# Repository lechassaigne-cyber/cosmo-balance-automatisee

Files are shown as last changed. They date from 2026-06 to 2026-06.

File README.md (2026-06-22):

# Système automatisé de pesée — Cosmo International Fragrances

> ⚠️ Projet en cours de développement — Stage avril–juillet 2026

**Auteur :** Léo Chassaigne  
**Période :** Avril – Juillet 2026  
**Entreprise :** Cosmo International Fragrances — Mougins (06)  
**Formation :** CESI École d'Ingénieurs — Spécialité Systèmes Électroniques et Électriques Embarqués (S3E)

---

## Contexte

Projet développé dans le cadre d'un stage de deuxième année au sein de la division Technology de Cosmo International Fragrances. L'objectif est de concevoir un système automatisé de pesée permettant de suivre l'évaporation de flacons de parfum au fil du temps, en remplacement des relevés manuels effectués par les équipes du laboratoire.

---

## Historique des versions

### V1 — Python / Mini Unit Scale (I2C)
Première version développée en Python sur Wio Terminal.  
Utilise des balances Mini Unit Scale communicantes via un bus I2C multiplexé (TCA9548A).  
Fonctionnelle sur 4 balances simultanées.

### V2 — Python / HX711
Remplacement des Mini Unit Scale par des cellules de charge associées à des modules HX711.  
Amélioration de la stabilité des mesures.  
Toujours en Python sur Wio Terminal.

### V3 — C++ / HX711 / reTerminal ← version actuelle
Réécriture complète du firmware en C++ sous PlatformIO (framework Arduino).  
Communication BLE Nordic UART Service vers le reTerminal (Raspberry Pi CM4).  
Réception et enregistrement automatique des données en CSV sur le reTerminal.  
Dashboard TFT sur le Wio Terminal (mode OVERVIEW / FOCUS).

---

## Matériel utilisé

| Composant | Rôle |
|---|---|
| Wio Terminal (Seeed Studio) | Microcontrôleur principal, affichage TFT, BLE |
| reTerminal (Raspberry Pi CM4) | Réception BLE, stockage CSV |
| Cellules de charge 1 kg | Mesure du poids |
| Modules HX711 | Amplification signal cellules de charge |
| TCA9548A | Multiplexeur I2C (jusqu'à 8 canaux) |
| Boîtier Fusion 360 | Impression 3D sur mesure |

---

## Architecture actuelle (V3)
Cellules de charge (x4 actuellement)

↓ signal analogique

HX711 (x4)

↓ signal numérique

Wio Terminal (C++ / PlatformIO)

Lecture HX711
Affichage TFT (OVERVIEW / FOCUS)
Émission BLE Nordic UART

↓ Bluetooth

reTerminal (Raspberry Pi CM4)
Réception BLE
Enregistrement CSV horodaté

---

## Fonctionnalités implémentées

- Lecture simultanée de 4 balances HX711
- Affichage TFT : mode OVERVIEW (4 balances) et mode FOCUS (1 balance détaillée)
- Tare et calibration individuelle par masse étalon de 100 g
- Transmission BLE Nordic UART Service vers reTerminal
- Enregistrement automatique en CSV horodaté sur reTerminal

---

## Fonctionnalités en développement

- [ ] Support de 12 balances simultanées (extension multiplexage HX711)
- [ ] Montée en charge vers 20+ balances
- [ ] Interface web de visualisation des données en temps réel
- [ ] Alertes automatiques en cas de dérive anormale

---

## Branchement V3 (4 balances)

| Signal | Broche Wio Terminal |
|---|---|
| SCK commun | D0 |
| DOUT Balance 1 | D1 |
| DOUT Balance 2 | D2 |
| DOUT Balance 3 | D3 |
| DOUT Balance 4 | D4 |
| Alimentation | 3,3 V |
| Masse | GND |

---

## Structure du repo
/v1_python_mini_scales/   → V1 Python + Mini Unit Scale

/v2_cpp_hx711/            → V2 Python + HX711

/v3_reterminal/           → V3 C++ + HX711 + reTerminal (actuelle)

/docs/                    → Schémas, Gantt, documentation

---

## Statut

🟡 En cours — objectif : 12 balances fonctionnelles puis interface web

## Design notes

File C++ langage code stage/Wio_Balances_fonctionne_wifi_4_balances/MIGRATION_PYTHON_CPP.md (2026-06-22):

# Migration Python → C++ : tableau de correspondance

Ce guide montre ligne par ligne comment ton code Python a été traduit en C++.

---

## Correspondances directes Python → C++

| Python | C++ |
|---|---|
| `time.monotonic()` | `millis()` (en millisecondes) |
| `time.sleep(0.01)` | `delay(10)` |
| `DISPLAY_PERIOD_S = 0.25` | `#define DISPLAY_PERIOD_MS 250` |
| `DEBOUNCE_S = 0.15` | `#define DEBOUNCE_MS 150` |
| `[0.0] * NB_SCALES` | `float arr[NB_SCALES] = {0.0f, ...}` |
| `btn.pull = Pull.UP` | `pinMode(pin, INPUT_PULLUP)` |
| `not btn.value` | `digitalRead(pin) == LOW` |
| `class ButtonEdge:` | `struct ButtonEdge { ... }` |
| `def fell(self):` | `bool fell() { ... }` |
| `digitalio.DigitalInOut(pin)` | `pinMode(pin, OUTPUT)` |
| `common_clock.value = False` | `digitalWrite(COMMON_SCK_PIN, LOW)` |
| `hx711 = HX711(data, clock)` | `scales[i].begin(DOUT_PINS[i], COMMON_SCK_PIN)` |
| `channel.value` | `scales[i].read()` |
| `Serial.println(...)` | `Serial.println(...)` (identique!) |
| `"B{}: {:7.2f} g".format(i, v)` | `printf("B%d: %7.2f g", i, v)` |
| `abs(weight) < ZERO_DEADBAND_G` | `abs(weight) < ZERO_DEADBAND_G`  (identique) |
| `mode = "OVERVIEW"` / `"FOCUS"` | `bool mode_focus = false` / `true` |
| `active_scale = (active_scale + 1) % NB_SCALES` | identique en C++ |

---

## Différences importantes à connaître

### 1. Les types de données sont explicites en C++

```python
# Python : type automatique
poids = 48.32
nb = 5
```

```cpp
// C++ : tu déclares le type
float poids = 48.32f;   // le 'f' dit que c'est un float (pas double)
int   nb    = 5;
```

### 2. Les tableaux ont une taille fixe

```python
# Python : liste dynamique, peut grandir
tare_offsets = [0.0] * 4
tare_offsets.append(0.0)  # possible
```

```cpp
// C++ : taille fixe déclarée à la création
float tare_offsets[4] = {0.0f, 0.0f, 0.0f, 0.0f};
// impossible d'ajouter des éléments après !
```

### 3. Les chaînes de caractères

```python
# Python : format() ou f-strings
msg = "B{}: {:7.2f} g".format(i + 1, poids)
msg = f"B{i+1}: {poids:.2f} g"
```

```cpp
// C++ : snprintf (pour char[]) ou printf/tft.printf
char msg[32];
snprintf(msg, sizeof(msg), "B%d: %7.2f g", i + 1, poids);

// ou directement sur l'écran :
tft.printf("B%d: %7.2f g", i + 1, poids);
```

### 4. Les classes → structures (struct)

```python
# Python
class ButtonEdge:
    def __init__(self, btn):
        self.btn = btn
        self.last_state = pressed(btn)

    def fell(self):
        ...

btn_a = ButtonEdge(BTN_A)
```

```cpp
// C++
struct ButtonEdge {
    int  pin;
    bool last_state;

    void begin(int p) { ... }  // équivalent de __init__
    bool fell() { ... }
};

ButtonEdge btn_a;
btn_a.begin(WIO_KEY_A);
```

### 5. millis() vs time.monotonic()

```python
# Python : secondes flottantes
now = time.monotonic()            # ex: 123.456
if now - last_update >= 0.25:    # 0.25 secondes
    last_update = now
```

```cpp
// C++ : millisecondes entières
uint32_t now = millis();               // ex: 123456
if (now - last_display_ms >= 250) {   // 250 ms
    last_display_ms = now;
}
```

### 6. #define vs les constantes Python

```python
# Python
NB_SAMPLES = 5
ZERO_DEADBAND_G = 0.05
```

```cpp
// C++ : deux façons
#define NB_SAMPLES 5              // remplacement textuel avant compilation
const float ZERO_DEADBAND_G = 0.05f;  // vraie constante typée (préférable)
```

---

## Structure des bibliothèques à installer

### Dans Arduino IDE :
1. Ouvre Outils → Gérer les bibliothèques
2. Installe :
   - `HX711 by bogde`
   - `Seeed Arduino TFT_eSPI` (déjà incluse si tu as configuré le Wio Terminal)
   - `Seeed Arduino rpcWiFi` (idem)

### Dans PlatformIO (VS Code) :
Tout est dans platformio.ini, c'est automatique.

---

## Pour tester étape par étape

1. **D'abord sans WiFi** : commente `setup_wifi()` dans `setup()` et teste que les balances fonctionnent exactement comme en Python.

2. **Ensuite ajoute le WiFi** : décommente `setup_wifi()`, mets tes identifiants, et vérifie l'IP dans le Serial Monitor.

3. **Test depuis navigateur** : ouvre `http://<ip>/data` dans Safari sur iPhone → tu dois voir le JSON.

4. **Enfin l'app iOS** : entre l'IP dans les réglages de l'app.

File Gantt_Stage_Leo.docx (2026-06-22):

# Diagramme de Gantt — Stage Léo

Projet : Extension du système de balances I²C (Wio Terminal + TCA9548A + M5Stack MiniScales)

Objectif : Passer de 5 balances à 56 balances (7 × TCA9548A × 8 canaux) en 3 mois, par montée progressive 16 → 32 → 56 voies.

| MOIS 1 | | | | MOIS 2 | | | | MOIS 3
Tâche / Activité | S1 | S2 | S3 | S4 | S5 | S6 | S7 | S8 | S9 | S10 | S11 | S12 | Livrables & Jalons

🔹 MOIS 1 — Multi-mux + PoC 16 voies (Objectif : preuve de faisabilité)
S1 — Onboarding & cadrage
Lire et annoter le script existant
Définir les critères de succès (nb voies, débit, latence…)
S2 — Refactor minimal
Isoler 4 blocs : MuxManager, ScaleInventory, UI, Logger
Introduire le type d'ID interne (mux_addr, channel)
S3 — Multi-mux detection + scan
Remplacer detect_tca_addr() par detect_tca_addrs()
Scanner (mux_addr, ch) + probe registre poids 0x10
S4 — PoC 16 voies + optimisation performance
Tester avec 2 mux (16 canaux) et 8–16 balances
Mesurer temps : switch mux, canal, lecture weight/adc
Réduire/adapter le sleep(0.08) après sélection canal
✅ JALON V1 — 12–16 balances, stable 1h, CSV (mux_addr, ch) | | | | | | | | | | | | | ✅ Jalon de validation

🔹 MOIS 2 — 56 voies + Calibration persistée + Robustesse
S5 — Passage 56 voies (hardware + software)
Montée progressive : 3 → 5 → 7 mux (TCA9548A)
UI overview paginée (8–12 balances/page)
S6 — Calibration persistée
Fichier /sd/calibration.json indexé par (mux_addr, ch)
Stocker : tare, gain, mode 2pt/3pt, σ Welford, date, N
Rechargement au boot → LED verte/rouge cohérente
S7 — Batch calibration
Assistant séquentiel : calibrer liste de balances en série
Réutiliser routine avg + σ Welford + progression UI
S8 — Robustesse I²C & gestion erreurs
Compteurs d'erreurs par voie + retry intelligent
État 'quarantaine' + rescan périodique des voies
✅ JALON V2 — 32+ balances, calib persistée, batch calib, 24h sans freeze | | | | | | | | | | | | | ✅ Jalon de validation

🔹 MOIS 3 — Industrialisation & Validation endurance
S9 — Logging scalable (double mode)
Mode Overview : 0.5–1 Hz, toutes voies
Mode Focus : 5–10 Hz, voie active
Rotation fichiers /sd/log_YYYYMMDD.csv + en-tête
S10 — UX 'atelier'
Écran diagnostic : mux détectés, erreurs I²C, SD OK/KO
Écran 'non calibrées' + raccourci batch calib
S11 — Tests d'endurance (24–72 h)
Test continu : dérive, σ post-calibration, erreurs cumulées
Surveillance SD : pertes, corruptions
S12 — Packaging & Release
Procédure mise en service : adressage mux, câblage, checklist
Release Candidate + tag version
✅ JALON V3 (FINAL) — 50–56 balances, 72h stable, UI atelier, dossier validation | | | | | | | | | | | | | ✅ Jalon de validation

Légende : | Mois 1 | Mois 2 | Mois 3 | Livrables | Jalons ✅

Architecture cible : Wio Terminal ↔ I²C 100 kHz ↔ 7× TCA9548A (0x70–0x77) ↔ 56× M5Stack MiniScale (0x26)

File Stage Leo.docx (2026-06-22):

1) Description de l’appareil actuel (déduite du code)

1.1. Plateforme & interfaces

- Contrôleur principal : Seeed Wio Terminal (CircuitPython) avec écran intégré piloté via displayio et terminalio.
- Entrées utilisateur : boutons A/B/C + joystick (UP/DOWN/LEFT/RIGHT/PRESS), lus via DigitalInOut en pull-up (actif bas) + petit debounce logiciel.
- Bus capteurs : I²C sur board.SCL/board.SDA à 100 kHz.
- Stockage : option de microSD (via sdcardio + storage) pour logger un CSV.

1.2. Balances supportées actuellement

- Le script est conçu pour des M5Stack Unit Mini Scales (ou compatibles UIFlow) pilotées en I²C à l’adresse 0x26.
- Les registres utilisés suggèrent un module “intelligent” (poids en float, ADC, LED, filtres, etc.) :
  - REG_WEIGHT = 0x10, REG_ADC = 0x00, REG_LED = 0x30, REG_LPF/AVG/EMA = 0x80..0x82, etc.
- Objectif actuel : jusqu’à 5 balances (ciblage explicite TARGET_COUNT = 5) sur un multiplexeur I²C.

1.3. Multiplexage I²C (raison clé du design)

- Le code utilise un TCA9548A (switch I²C 8 canaux) pour gérer plusieurs balances ayant la même adresse I²C (0x26).
- Il y a une auto-détection du TCA : scan I²C et recherche d’une adresse dans 0x70..0x77.
- Le code scanne ensuite les 8 canaux du TCA et “probe” une balance en lisant effectivement le registre poids (0x10) pour valider la présence.
- Un wrapper MuxChannel encapsule la sélection de canal, avec une attention “lock-safe” (éviter les erreurs de lock I²C).

➡️ Interprétation matérielle actuelle :
Wio Terminal ⇄ (I²C) ⇄ 1× TCA9548A ⇄ (8 sous-bus I²C) ⇄ jusqu’à 5 modules MiniScale (addr 0x26 chacun).

1.4. Fonctionnalités “produit” déjà présentes

Affichage / UI

- Écran avec un titre “Mini Scales x5 (TCA9548A)” + affichage canal actif, poids, ADC, état filtres, état calibration, liste, hints.
- Navigation : LEFT/RIGHT pour changer la balance active ; A/B/C/PRESS pour tare, calibration, réglages, log (d’après hints).

Filtres

- Paramètres de filtrage exposés (EMA alpha, average level, low-pass filter) + réglages par balance et globaux (ALL) via appui long sur A.

Calibration

- Deux modes : 2 points et 3 points (0 g / 100 g / 1000 g) annoncés dans l’en-tête.
- Calibration basée sur moyenne de N échantillons (100/300/500/1000) avec estimation de σ via Welford (online variance) et progression UI.
- Indication “SPS hint” 10 ou 80 (HX711 typiquement), et SAMPLE_DELAY = 1/SPS_HINT.

LED d’état

- LED verte si calibrée, rouge sinon + test RGB/GRB (ordre des couleurs configurable). Logging
- Log CSV sur SD : /sd/miniscales_log.csv avec colonnes t_monotonic_s,channel,weight_g,adc et période typique 0.2 s (5 Hz).

2) Ce qui limite le passage à >50 balances (diagnostic)

À partir du code, les “verrous” sont surtout architecturaux :

1. Un seul multiplexeur TCA9548A géré Le code détecte une seule adresse TCA (detect_tca_addr renvoie un unique MUX_ADDR) et scanne 8 canaux. ➡️ Pour >50 balances, il faut soit plusieurs TCA9548A (adresses distinctes), soit une architecture différente.
2. Modèle de données “balance = canal (0..7)” Aujourd’hui une balance est identifiée par son canal TCA (et implicitement un seul TCA). ➡️ Avec plusieurs multiplexeurs, l’ID doit devenir (adresse_mux, canal) voire un identifiant logique persisté.
3. UI conçue pour ~5 balances Le titre et la logique “balance active” + listage sont orientés petit nombre. ➡️ À 50+, il faut pagination, recherche, groupes, ou une UI “tableau”.
4. Débit / latence I²C + logging À 5 Hz, loguer 50 balances => 250 lignes/s. Même si ça peut passer, il faut contrôler :
- temps de sélection mux (le code met 80 ms de stabilisation après select canal) ➡️ 80 ms × 50 = 4 s rien que de “stabilisation” si on garde ce chiffre tel quel → impossible. => Il faudra réviser la stratégie de lecture (stabilisation plus courte, lecture par batch, ou “stabilisation only on channel switch”, etc.)

3) Feuille de route 3 mois (objectif : >50 HX711)

Je propose une feuille de route robuste en 3 phases, avec jalons “démontrables” chaque mois.

Je donne deux scénarios matériels, car “HX711” peut signifier soit (A) vos MiniScale I²C (avec HX711 interne) soit (B) des HX711 bruts (DOUT/SCK). Le code actuel correspond clairement au scénario A.

3.A Scénario A (recommandé si vous gardez les “Unit Mini Scales” I²C)

Architecture cible

- Mettre 7× TCA9548A (7 adresses différentes parmi 0x70..0x77) sur le même I²C maître
- Chaque TCA gère 8 canaux → 56 emplacements possibles (>50).
- Chaque balance reste à 0x26 mais isolée par canal/mux.

Mois 1 — Refactor + multi-mux + PoC 16 balances

Objectif démontrable (fin M1) : 2 multiplexeurs (16 canaux) détectés et 12–16 balances lues de façon stable.

1. Refactor logiciel (1 semaine)
- Extraire en modules :
  - MuxManager : scan des mux (0x70..0x77), sélection (addr + channel)
  - ScaleManager : inventaire, lecture, erreurs, statut calibré
  - UI : navigation/pagination
  - Logger : file/flush/rotation
- Remplacer l’ID “channel” par (mux_addr, channel) partout (UI + log). (Aujourd’hui le log ne contient que channel.)
1. Multi-mux detection (1 semaine)
- Remplacer detect_tca_addr() (unique) par detect_tca_addrs() (liste). Le code scanne déjà les adresses 0x70..0x77 : on réutilise, mais sans “return au premier”.
1. PoC performance (1 semaine)
- Mesurer le temps réel d’une lecture (select mux + select channel + read weight/adc).
- Réduire/supprimer le time.sleep(0.08) de stabilisation si non nécessaire (ou le rendre adaptatif).
1. UI minimale adaptée (1 semaine)
- Pagination : afficher 8–12 balances par page, un curseur, et la balance active détaillée.

Livrables M1

- Firmware PoC + note technique “multi-mux”
- Log CSV enrichi : t, mux_addr, channel, weight_g, adc
- Test bench 16 voies stable 1h

Mois 2 — Passage 56 voies + calibration persistée + batch calibration

Objectif démontrable (fin M2) : 56 voies détectées (ou au moins 50), lecture et logging stables, calibration utilisable en prod.

1. Calibration persistée (1–2 semaines)
- Stocker les paramètres de calibration par balance (ID = mux+channel) dans un fichier sur SD :
  - offset/tare
  - gap/scale factor
  - mode 2-pt ou 3-pt
  - date, σ estimé, N échantillons Le code a déjà la logique “N échantillons + σ Welford”.
1. Batch calibration (1 semaine)
- “Assistant” : calibrer une liste (ex. balances 1–10) en série
- Afficher progression globale + gestion erreurs (balance absente, instable, etc.)
1. Robustesse I²C & erreurs (1 semaine)
- Compteurs d’erreurs par balance
- Retry exponentiel
- “quarantaine” d’une voie défaillante
- Re-scan périodique des voies

Livrables M2

- Banc 50–56 voies câblé
- Calibration persistée + assistant “batch”
- Logging stable (débit validé)

Mois 3 — Industrialisation (UX, tests longs, maintenance)

Objectif démontrable (fin M3) : outil utilisable au quotidien, avec tests d’endurance et procédure de mise en service.

1. Optimisation du logging
- Mode “snapshot” (ex: 1 Hz sur 56 voies) + mode “focus” (10 Hz sur 1 voie active)
- Rotation fichiers (par jour / par run) + en-tête métadonnées
1. Ergonomie
- Écran “overview” : min/max, alarmes, dérive
- Écran “diagnostic” : bus, mux, erreurs, SD
1. Validation
- Test 24–72 h
- Mesure de dérive / bruit (σ) déjà calculé pendant calibration : réutiliser pour qualification.

Livrables M3

- “Release candidate” firmware
- Procédure d’assemblage câblage + checklist validation
- Rapport de test endurance

1) Cible matérielle recommandée (>50 balances I²C)

1.1. Principe

Votre code utilise déjà un TCA9548A (8 canaux) pour isoler des périphériques ayant la même adresse I²C (0x26).
Pour dépasser 50 balances, la voie la plus simple et cohérente est :

- 7× TCA9548A sur le bus I²C maître, chacun avec une adresse différente dans la plage 0x70..0x77. (8 adresses possibles → 8 mux max).
- Chaque TCA fournit 8 sous-bus → 7×8 = 56 emplacements (objectif >50 atteint).
- Chaque balance reste à l’adresse 0x26 mais isolée par (adresse_mux, canal).

👉 Nouvel identifiant canonique d’une balance : (mux_addr, channel) au lieu de channel seul. (Votre script journalise aujourd’hui uniquement channel dans le CSV.)

1.2. Points d’attention “terrain” (très importants à 50+)

À 56 modules, les problèmes classiques sont : alimentation, masse, câblage I²C, pull-ups et capacité de bus. Le multiplexage aide, mais l’amont (bus maître) voit quand même 7 mux.

Recommandations pratiques (non-intrusives) :

- Alimentation : prévoir une distribution 5V stable (courant total) + découplage local (100 nF + 10 µF) au plus près de chaque mux et de chaque groupe de balances.
- I²C : garder SCL/SDA “tronc commun” court, puis dériver vers les mux ; sur chaque canal, câbles courts vers les balances.
- Pull-ups : éviter d’empiler des pull-ups sur chaque module ; idéalement un jeu de pull-ups bien dimensionné sur le bus maître (et éventuellement par canal si nécessaire).

2) Évolutions logicielles nécessaires (à partir de votre script)

2.1. Ce que fait déjà le script (base solide)

- Détection du TCA par scan I²C sur 0x70..0x77, mais il s’arrête au premier trouvé.
- Scan des canaux (0..7) du TCA puis probe d’une balance en lisant effectivement le registre poids 0x10 à l’adresse 0x26.
- Construit une liste scales de type [channel, MiniScale, led_order, calibrated_bool].
- UI (Wio Terminal) + joystick/boutons + réglages par balance / globaux, calibration (2-pt / 3-pt), calcul σ Welford, et log CSV sur SD.

2.2. Ce qu’il faut changer pour 56 voies

A) Multi-mux : détecter tous les TCA au lieu d’un seul

Aujourd’hui : detect_tca_addr() renvoie un seul MUX_ADDR.
Demain : detect_tca_addrs() doit renvoyer une liste d’adresses mux trouvées sur 0x70..0x77. (https://uniqueyanbal-my.sharepoint.com/personal/antoine_gouteyron_cosmo-fragrances_com/Documents/Fichiers%20Microsoft%20Copilot%20Chat/CIPY_5SCALES_3CALIB_V2.py)

B) Scanner toutes les voies : (mux_addr, channel)

Aujourd’hui : detect_scale_channels() scanne 8 canaux d’un mux.
Demain : il faut boucler sur tous les mux détectés puis leurs canaux, et construire une liste de tuples [(mux_addr, ch), ...]. (https://uniqueyanbal-my.sharepoint.com/personal/antoine_gouteyron_cosmo-fragrances_com/Documents/Fichiers%20Microsoft%20Copilot%20Chat/CIPY_5SCALES_3CALIB_V2.py)

C) Représentation interne : ScaleID

Changer la structure scales de :

- scales[i] = [ch, MiniScale, led_order, calibrated] vers : (https://uniqueyanbal-my.sharepoint.com/personal/antoine_gouteyron_cosmo-fragrances_com/Documents/Fichiers%20Microsoft%20Copilot%20Chat/CIPY_5SCALES_3CALIB_V2.py)
- scales[i] = [mux_addr, ch, MiniScale, led_order, calibrated, stats...]

Cela impacte :

- UI (affichage de l’ID)
- Log CSV (ajouter mux_addr)
- Calibration persistée (fichier de paramètres indexé par ID)

D) Performance : supprimer la latence “80 ms” par switch de canal

Votre code impose time.sleep(0.08) à chaque tca_select_channel().
Avec 56 voies, ça devient rédhibitoire (56×80 ms ≈ 4,5 s de “délai” par tour).
=> Il faudra : (https://uniqueyanbal-my.sharepoint.com/personal/antoine_gouteyron_cosmo-fragrances_com/Documents/Fichiers%20Microsoft%20Copilot%20Chat/CIPY_5SCALES_3CALIB_V2.py)

- rendre ce délai configurable,
- et idéalement beaucoup plus faible (ou uniquement appliqué après un changement de mux, ou si lecture invalide).

E) UI : passer de “5 balances” à “liste paginée”

Votre UI est pensée pour TARGET_COUNT=5 et navigation simple.
Pour 56 balances, il faut : (https://uniqueyanbal-my.sharepoint.com/personal/antoine_gouteyron_cosmo-fragrances_com/Documents/Fichiers%20Microsoft%20Copilot%20Chat/CIPY_5SCALES_3CALIB_V2.py)

- un écran overview paginé (ex : 10–12 balances par page),
- un écran focus (1 balance) pour réglages/calibration,
- un mécanisme de filtre (balances actives seulement / en erreur / non calibrées).

F) Logging : ajouter mux + modes d’échantillonnage

Aujourd’hui log CSV : t_monotonic_s,channel,weight_g,adc à période LOG_PERIOD=0.2.
Pour 56 voies, prévoir deux modes : (https://uniqueyanbal-my.sharepoint.com/personal/antoine_gouteyron_cosmo-fragrances_com/Documents/Fichiers%20Microsoft%20Copilot%20Chat/CIPY_5SCALES_3CALIB_V2.py)

- Overview : 0.5–1 Hz sur toutes les voies
- Focus : 5–10 Hz sur la voie active (ou un petit groupe)

Et enrichir le CSV :

- t, mux_addr, channel, weight_g, adc, flags...

G) Calibration persistée (indispensable en prod)

Votre code gère calibration/σ et LED d’état (vert/rouge) mais ne montre pas explicitement de persistance dans un fichier de calibration.
Pour 56 voies, c’est indispensable : (https://uniqueyanbal-my.sharepoint.com/personal/antoine_gouteyron_cosmo-fragrances_com/Documents/Fichiers%20Microsoft%20Copilot%20Chat/CIPY_5SCALES_3CALIB_V2.py)

- un fichier /sd/calibration.json (ou CSV) indexé par (mux_addr, ch)
- stocker : tare/offset, gap/factor, mode 2pt/3pt, date, N, σ

3) Feuille de route “3 mois” (découpée semaine par semaine)

Hypothèse : le stagiaire est dédié majoritairement à ce projet et vous pouvez valider du hardware au fil de l’eau.

Mois 1 — “Multi-mux + PoC 16 voies” (objectif : preuve de faisabilité)

S1 — Onboarding & cadrage

- Lire/annoter le script : pipeline I²C→TCA→probe→MiniScale, UI, calibration, log. (https://uniqueyanbal-my.sharepoint.com/personal/antoine_gouteyron_cosmo-fragrances_com/Documents/Fichiers%20Microsoft%20Copilot%20Chat/CIPY_5SCALES_3CALIB_V2.py)
- Définir les critères de succès : nb voies, fréquence log (overview/focus), temps de scan, temps de boot, tolérance erreurs.

S2 — Refactor minimal “propre”

- Isoler 4 blocs : MuxManager, ScaleInventory, UI, Logger.
- Introduire un type d’ID interne (mux_addr, channel).

S3 — Multi-mux detection + scan

- Implémenter scan de tous les mux sur 0x70..0x77 (au lieu d’un seul). (https://uniqueyanbal-my.sharepoint.com/personal/antoine_gouteyron_cosmo-fragrances_com/Documents/Fichiers%20Microsoft%20Copilot%20Chat/CIPY_5SCALES_3CALIB_V2.py)
- Scanner (mux_addr, ch) et “probe” via lecture registre poids 0x10 à 0x26. (https://uniqueyanbal-my.sharepoint.com/personal/antoine_gouteyron_cosmo-fragrances_com/Documents/Fichiers%20Microsoft%20Copilot%20Chat/CIPY_5SCALES_3CALIB_V2.py)

S4 — PoC 16 voies + première optimisation perf

- Tester avec 2 mux (16 canaux) et 8–16 balances.
- Mesurer les temps : switch mux+canal, lecture weight/adc.
- Réduire/adapter le sleep(0.08) après sélection de canal. Livrable fin M1 : firmware PoC + log CSV contenant mux_addr + test stable 1–2h sur 16 voies. (https://uniqueyanbal-my.sharepoint.com/personal/antoine_gouteyron_cosmo-fragrances_com/Documents/Fichiers%20Microsoft%20Copilot%20Chat/CIPY_5SCALES_3CALIB_V2.py)

Mois 2 — “56 voies + calibration persistée + robustesse”

S5 — Passage 56 voies (hardware + software)

- Mettre 7 mux (ou montée progressive : 3 puis 5 puis 7).
- Implémenter une UI paginée (overview).

S6 — Calibration persistée

- Ajouter sauvegarde/chargement calibration par (mux_addr, ch).
- Rejouer calibration au boot → LED verte/rouge cohérente. (https://uniqueyanbal-my.sharepoint.com/personal/antoine_gouteyron_cosmo-fragrances_com/Documents/Fichiers%20Microsoft%20Copilot%20Chat/CIPY_5SCALES_3CALIB_V2.py)

S7 — Batch calibration (gain énorme de temps opérationnel)

- Assistant : calibrer en série une liste de balances sélectionnées.
- Exploiter votre routine “moyenne N + σ Welford + progression UI”. (https://uniqueyanbal-my.sharepoint.com/personal/antoine_gouteyron_cosmo-fragrances_com/Documents/Fichiers%20Microsoft%20Copilot%20Chat/CIPY_5SCALES_3CALIB_V2.py)

S8 — Robustesse I²C / gestion erreurs

- Retry intelligent (3 essais vous le faites déjà pour le probe). (https://uniqueyanbal-my.sharepoint.com/personal/antoine_gouteyron_cosmo-fragrances_com/Documents/Fichiers%20Microsoft%20Copilot%20Chat/CIPY_5SCALES_3CALIB_V2.py)
- Compteurs d’erreurs par voie + état “quarantaine” + rescan périodique. Livrable fin M2 : 50–56 balances détectées, calibration persistée, logging overview stable.

Mois 3 — “Industrialisation & validation endurance”

S9 — Logging scalable

- Deux modes :
  - Overview : 0.5–1 Hz toutes voies
  - Focus : 5–10 Hz voie active
- Rotation de fichiers (/sd/log_YYYYMMDD.csv) + en-tête.

S10 — UX “atelier”

- Écran diagnostic : mux trouvés, nb voies, erreurs I²C, SD OK/KO. (https://uniqueyanbal-my.sharepoint.com/personal/antoine_gouteyron_cosmo-fragrances_com/Documents/Fichiers%20Microsoft%20Copilot%20Chat/CIPY_5SCALES_3CALIB_V2.py)
- Écran “non calibrées” : liste prioritaire + raccourci batch calib.

S11 — Tests longs (24–72h)

- Endurance : vérifier pertes de SD, corruptions, dérives.
- Exploiter σ mesurée à la calibration comme indicateur qualité. (https://uniqueyanbal-my.sharepoint.com/personal/antoine_gouteyron_cosmo-fragrances_com/Documents/Fichiers%20Microsoft%20Copilot%20Chat/CIPY_5SCALES_3CALIB_V2.py)

S12 — Packaging

- Procédure mise en service : adressage mux, câblage, checklist.
- “Release Candidate” + tag version. Livrable fin M3 : outil utilisable quotidiennement + dossier validation.

4) Risques & “garde-fous” (pour tenir les 3 mois)

Risque #1 : latence par commutation de canal

Votre sleep(0.08) par commutation doit devenir non bloquant / réduit / conditionnel, sinon 56 voies seront trop lentes. (https://uniqueyanbal-my.sharepoint.com/personal/antoine_gouteyron_cosmo-fragrances_com/Documents/Fichiers%20Microsoft%20Copilot%20Chat/CIPY_5SCALES_3CALIB_V2.py)

Garde-fou : dès M1-S4, mesurez et fixez une cible (ex : tour complet overview < 1 s à 1 Hz).

Risque #2 : instabilités I²C (câbles, pull-ups, bruit)

À 56 modules, il faut prévoir du temps de debug hardware.

Garde-fou : ajout d’un écran diagnostic + logs d’erreurs par voie (S8–S10).

Risque #3 : calibration opérationnelle trop lourde

Sans persistance + batch, la mise en service devient pénible.

Garde-fou : calibration persistée S6 + batch S7.

5) Ce que je ferais faire au stagiaire aujourd’hui (checklist “Jour 1”)

1. Lister ce qui est déjà “réutilisable tel quel” : UI framework, debouncers, logger SD, wizard calibration (concept), Welford σ. (https://uniqueyanbal-my.sharepoint.com/personal/antoine_gouteyron_cosmo-fragrances_com/Documents/Fichiers%20Microsoft%20Copilot%20Chat/CIPY_5SCALES_3CALIB_V2.py)
2. Créer une branche “multi-mux” et implémenter :
  - scan de toutes les adresses mux (0x70..0x77) (https://uniqueyanbal-my.sharepoint.com/personal/antoine_gouteyron_cosmo-fragrances_com/Documents/Fichiers%20Microsoft%20Copilot%20Chat/CIPY_5SCALES_3CALIB_V2.py)
  - scan complet (mux_addr, ch) avec probe sur registre poids 0x10 (https://uniqueyanbal-my.sharepoint.com/personal/antoine_gouteyron_cosmo-fragrances_com/Documents/Fichiers%20Microsoft%20Copilot%20Chat/CIPY_5SCALES_3CALIB_V2.py)
3. Modifier le CSV pour inclure mux_addr. (Aujourd’hui il n’y a que channel.)

Cible finale (à garder en tête)

- 56 balances max (7 × TCA9548A × 8 canaux)
- Identification stable de chaque balance : (mux_addr, channel)
- 2 modes de lecture :
  - Overview : toutes les balances, fréquence faible
  - Focus : 1 balance (ou petit groupe), fréquence élevée
- Calibration persistée, batchable
- Logging robuste SD et communication BLE
- UI exploitable en atelier

Architecture matérielle cible (inchangée à chaque étape)

Élément | Final
Contrôleur | Wio Terminal
Bus maître | I²C 100 kHz
Multiplexeurs | TCA9548A (addr 0x70–0x77)
Balances | M5Stack Unit Mini Scales (I²C addr 0x26)
NB max | 7 mux × 8 canaux = 56 voies

Chaque montée en charge ajoute simplement des mux, sans remise en cause du design. (https://uniqueyanbal-my.sharepoint.com/personal/antoine_gouteyron_cosmo-fragrances_com/Documents/Fichiers%20Microsoft%20Copilot%20Chat/CIPY_5SCALES_3CALIB_V2.py)

Roadmap progressive avec jalons de validation

🔹 Étape 1 — 16 balances (Mois 1)

➡️ Preuve de faisabilité + refonte logicielle propre

Matériel

- ✅ 2 × TCA9548A (ex. 0x70, 0x71)
- ✅ Jusqu’à 16 Unit Mini Scales

Objectifs techniques

1. Passer de 1 mux → N mux
2. Passer de channel → (mux_addr, channel)
3. Avoir un système stable et mesuré

Travaux à réaliser

1. Détection multi-mux

- Remplacer detect_tca_addr() par detect_tca_addrs()
- Scanner toutes les adresses 0x70..0x77, non plus la première trouvée (https://uniqueyanbal-my.sharepoint.com/personal/antoine_gouteyron_cosmo-fragrances_com/Documents/Fichiers%20Microsoft%20Copilot%20Chat/CIPY_5SCALES_3CALIB_V2.py)

2. Inventaire des balances

- Boucle :
- pour chaque mux_addr
- pour channel 0..7
- tca_select(mux_addr, channel)
- probe registre poids (0x10 @ 0x26)
- Construction d’une table :
- ScaleID = (mux_addr, channel)

3. Refactor minimal des structures

- scales = [{id, MiniScale, calibrated, stats, errors…}]
- Impact :
  - UI
  - CSV log
  - calibration

4. Mesure performance

- Mesurer le temps réel :
  - sélection mux
  - sélection canal
  - lecture WEIGHT / ADC
- Remettre en cause le sleep(0.08) systématique (inacceptable à 50+) (https://uniqueyanbal-my.sharepoint.com/personal/antoine_gouteyron_cosmo-fragrances_com/Documents/Fichiers%20Microsoft%20Copilot%20Chat/CIPY_5SCALES_3CALIB_V2.py)

✅ Jalon de validation V1 (GO / NO-GO)

- ✅ 12–16 balances détectées automatiquement
- ✅ Lecture stable pendant ≥ 1 h
- ✅ CSV contenant (mux_addr, channel, weight, adc)
- ✅ Temps d’un “tour overview” < 300 ms

🔹 Étape 2 — 32 balances (Mois 2)

➡️ Scalabilité + calibration exploitable

Matériel

- ➕ +2 TCA9548A (total 4 mux → 32 voies)

Objectifs techniques

1. UI adaptée à liste longue
2. Calibration persistée
3. Gestion des erreurs

Travaux à réaliser

1. UI “overview paginée”

- Liste de 8–10 balances par écran
- Code couleur :
  - vert = calibrée
  - rouge = non calibrée
  - orange = erreur I²C
- Navigation joystick UP/DOWN/PRESS (https://uniqueyanbal-my.sharepoint.com/personal/antoine_gouteyron_cosmo-fragrances_com/Documents/Fichiers%20Microsoft%20Copilot%20Chat/CIPY_5SCALES_3CALIB_V2.py)

2. Calibration persistée (indispensable)

- Fichier /sd/calibration.json ou .csv
- Clé = (mux_addr, channel)
- Stocker :
  - offset / tare
  - gain (gap)
  - mode 2pt / 3pt
  - σ (issu de Welford)
  - date / N échantillons (https://uniqueyanbal-my.sharepoint.com/personal/antoine_gouteyron_cosmo-fragrances_com/Documents/Fichiers%20Microsoft%20Copilot%20Chat/CIPY_5SCALES_3CALIB_V2.py)

3. Batch calibration

- Sélection : “balances non calibrées”
- Assistant séquentiel
- Réutilisation intégrale de votre code avg + σ Welford (https://uniqueyanbal-my.sharepoint.com/personal/antoine_gouteyron_cosmo-fragrances_com/Documents/Fichiers%20Microsoft%20Copilot%20Chat/CIPY_5SCALES_3CALIB_V2.py)

4. Robustesse

- Compteur d’erreurs par balance
- Retry intelligent
- Désactivation temporaire d’une voie instable

✅ Jalon de validation V2

- ✅ 32 balances actives
- ✅ Calibration sauvegardée / restaurée après reboot
- ✅ Batch calibration fonctionnelle
- ✅ Pas de freeze I²C sur 24 h de test

🔹 Étape 3 — 56 balances (Mois 3)

➡️ Industrialisation + endurance

Matériel

- ➕ +3 TCA9548A (total 7 → 56 voies)

Objectifs techniques

1. Séparation overview vs focus
2. Logging scalable
3. Validation longue durée

Travaux à réaliser

1. Double mode d’acquisition

- Overview :
  - 0.5–1 Hz
  - toutes balances
- Focus :
  - 5–10 Hz
  - balance active (ou petit groupe) (https://uniqueyanbal-my.sharepoint.com/personal/antoine_gouteyron_cosmo-fragrances_com/Documents/Fichiers%20Microsoft%20Copilot%20Chat/CIPY_5SCALES_3CALIB_V2.py)

2. Logging propre

- CSV :
- t, mux_addr, channel, weight_g, adc, flags
- Rotation automatique (par jour / par run)
- Flush maîtrisé (éviter usure SD)

3. Écran diagnostic

- Mux détectés
- Nombre de balances
- Erreurs I²C
- SD OK / KO (https://uniqueyanbal-my.sharepoint.com/personal/antoine_gouteyron_cosmo-fragrances_com/Documents/Fichiers%20Microsoft%20Copilot%20Chat/CIPY_5SCALES_3CALIB_V2.py)

4. Tests d’endurance

- 24–72 h en continu
- Surveillance :
  - dérive
  - σ post-calibration
  - erreurs cumulées

✅ Jalon de validation V3 (final)

- ✅ 50–56 balances stables
- ✅ Logging continu 72 h
- ✅ Redémarrage sans perte calibration
- ✅ UI exploitable sans PC

📋 Plan d’action Jour 1 – Semaine 1

Jour 1–2

- Lire et commenter le script existant
- Comprendre :
  - TCA9548A
  - adresse 0x26
  - registres MiniScale
  - calibration Welford
  - logger SD (https://uniqueyanbal-my.sharepoint.com/personal/antoine_gouteyron_cosmo-fragrances_com/Documents/Fichiers%20Microsoft%20Copilot%20Chat/CIPY_5SCALES_3CALIB_V2.py)

Jour 3–5

- Implémenter scan multi-mux
- Changer le CSV (mux_addr ajouté)
- Tester avec 2 mux only

👉 À la fin de la semaine 1, vous devez déjà avoir :

“Wio Terminal qui voit 2 mux + X balances, automatiquement, et loggue correctement”

✅ Conclusion (GO technique)

✅ Votre script actuel est une excellente base :

- le multiplexage,
- le probe actif,
- la calibration statistique,
- la structuration UI / log

sont exactement ce qu’il faut pour passer à 56 voies. (https://uniqueyanbal-my.sharepoint.com/personal/antoine_gouteyron_cosmo-fragrances_com/Documents/Fichiers%20Microsoft%20Copilot%20Chat/CIPY_5SCALES_3CALIB_V2.py)

➡️ La montée progressive 16 → 32 → 56 est la bonne stratégie, avec :

- risque maîtrisé,
- visibilité intermédiaire,
- valeur livrée à chaque jalon.

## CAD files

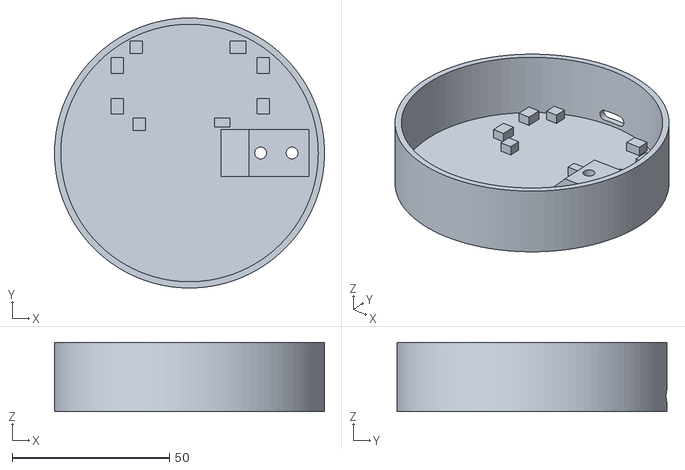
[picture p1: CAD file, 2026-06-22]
Modèles 3D Fusion/balance socle v4.stl
86.0 x 86.0 x 22.0

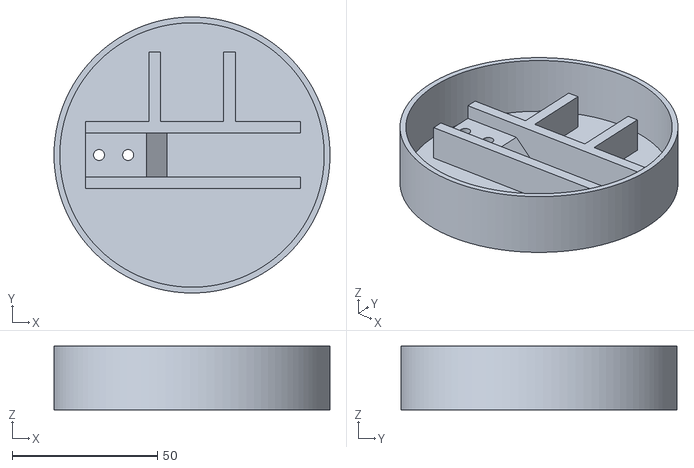
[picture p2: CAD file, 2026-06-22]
Modèles 3D Fusion/balance top trou de vis 10mm.stl
95.0 x 95.0 x 22.0

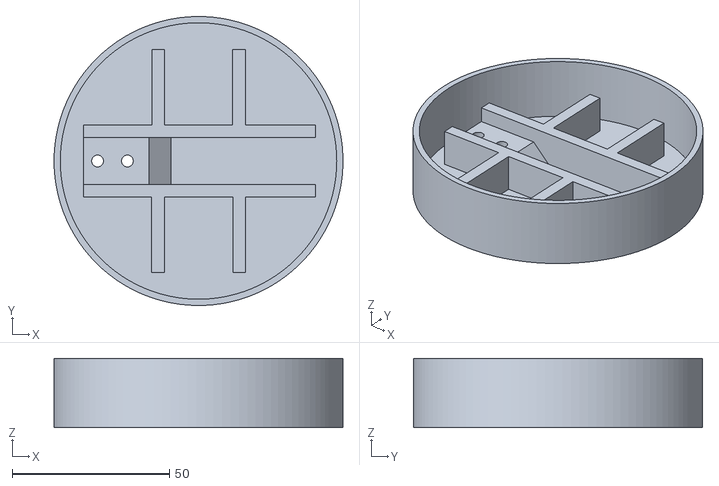
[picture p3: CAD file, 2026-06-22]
Modèles 3D Fusion/balance top v3.stl
92.0 x 92.0 x 22.0

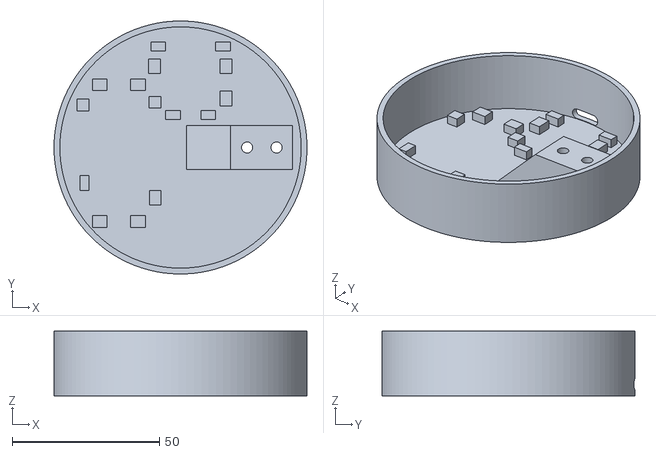
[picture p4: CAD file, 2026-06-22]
Modèles 3D Fusion/balance socle.stl
86.0 x 86.0 x 22.0

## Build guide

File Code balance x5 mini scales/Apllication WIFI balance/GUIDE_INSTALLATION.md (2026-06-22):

# Guide d'installation — App Balances Parfum

## Ce que tu as reçu
- `BalancesApp.swift`   — point d'entrée de l'app
- `Models.swift`        — structures de données
- `BalanceViewModel.swift` — logique WiFi + polling + alertes
- `ContentView.swift`   — toute l'interface utilisateur

---

## Étape 1 — Installer Xcode (Mac uniquement)

1. Ouvre le **Mac App Store**
2. Cherche **Xcode** et installe-le (gratuit, ~10 Go)
3. Lance Xcode une première fois pour qu'il installe ses composants

---

## Étape 2 — Créer un projet Xcode

1. Lance Xcode → **Create New Project**
2. Choisis : **iOS → App**
3. Remplis :
   - **Product Name** : `BalancesParfum`
   - **Interface** : SwiftUI
   - **Language** : Swift
   - **Team** : sélectionne ton Apple ID (gratuit !)
   - **Bundle Identifier** : `com.tonnom.balancesparfum`
4. Clique **Next** → choisis un dossier → **Create**

---

## Étape 3 — Ajouter les fichiers Swift

1. Dans Xcode, dans le panneau gauche tu vois un dossier `BalancesParfum`
2. **Supprime** le `ContentView.swift` existant (clic droit → Delete → Move to Trash)
3. Fais **glisser-déposer** tes 4 fichiers `.swift` dans ce dossier dans Xcode
4. Xcode te demande : coche **"Copy items if needed"** → **Finish**

---

## Étape 4 — Configurer iOS 16 minimum

Swift Charts nécessite iOS 16+.

1. Clique sur le projet (ligne bleue tout en haut dans le panneau gauche)
2. Onglet **General**
3. Rubrique **Minimum Deployments** → change en **iOS 16.0**

---

## Étape 5 — Autoriser HTTP (non-HTTPS)

Par défaut iOS bloque les connexions HTTP. Il faut l'autoriser pour ton réseau local.

1. Dans Xcode, ouvre le fichier **Info.plist**
2. Clic droit dans la liste → **Add Row**
3. Clé : `NSAppTransportSecurity` (type : Dictionary)
4. Dans ce dictionnaire, ajoute : `NSAllowsLocalNetworking` = **YES**

Ou directement en XML dans Info.plist :
```xml
<key>NSAppTransportSecurity</key>
<dict>
    <key>NSAllowsLocalNetworking</key>
    <true/>
</dict>
```

---

## Étape 6 — Lancer sur ton iPhone (GRATUIT)

1. Branche ton iPhone en USB
2. Sur l'iPhone : **Réglages → Confidentialité & sécurité → Mode développeur → Activer**
3. Dans Xcode en haut : sélectionne ton iPhone dans la liste des appareils
4. Clique ▶ (le bouton Play)
5. La première fois, Xcode te demande d'aller dans **Réglages iPhone → VPN et gestion des appareils** → fais confiance à ton certificat

---

## Étape 7 — Connecter l'app à ton Wio Terminal

1. Lance l'app sur ton iPhone
2. Va dans l'onglet **Réglages**
3. Entre l'adresse IP de ton Wio Terminal (ex: `192.168.1.100`)
4. Port : `80`
5. Clique **Appliquer** puis **Tester la connexion**

### Pour trouver l'IP du Wio Terminal :
Dans ton code Arduino/Wio, ajoute cette ligne et regarde le Serial Monitor :
```cpp
Serial.println(WiFi.localIP());
```

---

## Format JSON que le Wio Terminal doit renvoyer

Ton Wio Terminal doit servir un endpoint HTTP GET `/data` qui renvoie :

```json
{
  "timestamp": 1714300000,
  "balances": [
    {"id": 1, "name": "Flacon A", "weight": 48.32},
    {"id": 2, "name": "Flacon B", "weight": 62.15},
    {"id": 3, "name": "Flacon C", "weight": 23.89},
    {"id": 4, "name": "Flacon D", "weight": 55.10}
  ]
}
```

### Exemple minimal de code Wio Terminal (Arduino) :

```cpp
#include <WiFi.h>
#include <WebServer.h>
#include "HX711.h"

const char* ssid = "TON_WIFI";
const char* password = "TON_MOT_DE_PASSE";

WebServer server(80);
HX711 scales[4];  // configure tes 4 balances

// Pins DATA et CLK pour chaque HX711
// Adapte selon ton câblage !
const int DATA_PINS[] = {2, 4, 6, 8};
const int CLK_PINS[]  = {3, 5, 7, 9};

void setup() {
  Serial.begin(115200);
  WiFi.begin(ssid, password);
  while (WiFi.status() != WL_CONNECTED) { delay(500); }
  Serial.println(WiFi.localIP());  // ← note cette IP pour l'app

  // Initialise les 4 HX711
  for (int i = 0; i < 4; i++) {
    scales[i].begin(DATA_PINS[i], CLK_PINS[i]);
    scales[i].set_scale(/* ton facteur de calibration */);
    scales[i].tare();
  }

  // Route HTTP GET /data
  server.on("/data", HTTP_GET, []() {
    String json = "{\"timestamp\":" + String(millis()/1000) + ",\"balances\":[";
    const char* names[] = {"Flacon A","Flacon B","Flacon C","Flacon D"};
    for (int i = 0; i < 4; i++) {
      float w = scales[i].get_units(5);  // moyenne sur 5 lectures
      json += "{\"id\":" + String(i+1) + ",\"name\":\"" + names[i] + "\",\"weight\":" + String(w, 4) + "}";
      if (i < 3) json += ",";
    }
    json += "]}";
    server.send(200, "application/json", json);
  });

  server.begin();
}

void loop() {
  server.handleClient();
}
```

---

## Résumé des fonctionnalités de l'app

- ✅ Lecture temps réel des 4 balances via WiFi
- ✅ Graphique d'évolution du poids dans le temps
- ✅ Calcul automatique du taux d'évaporation (g/h)
- ✅ Alertes push quand un seuil est dépassé
- ✅ Export CSV par balance ou global
- ✅ Historique des mesures (jusqu'à 500 points par balance)
- ✅ Configuration IP/port depuis l'app
- ✅ Test gratuit sur iPhone avec Xcode (pas besoin de compte payant)

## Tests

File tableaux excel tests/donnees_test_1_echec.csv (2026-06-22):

Date/Heure | Balance 1 (g) | Balance 2 (g) | Balance 3 (g) | Balance 4 (g)
22/05/2026 11:53 | 299.78 | 300.2 | 0.0 | 0.0
22/05/2026 12:03 | 299.8 | 300.06 | 0.0 | 0.0
22/05/2026 12:16 | 299.79 | 300.22 | 0.0 | 0.0
22/05/2026 14:39 | 300.04 | 299.89 | 0.0 | 0.0
22/05/2026 16:48 | 299.26 | 310.75 | 0.0 | 0.0
22/05/2026 16:48 | 299.24 | 310.79 | 0.0 | 0.0
22/05/2026 16:49 | 299.23 | 310.77 | 0.0 | 0.0
26/05/2026 08:59 | 298.52 | 298.32 | 0.0 | 0.0
26/05/2026 08:59 | 298.52 | 298.17 | 0.0 | 0.0
26/05/2026 08:59 | 298.52 | 298.17 | 0.0 | 0.0
26/05/2026 08:59 | 298.52 | 298.09 | 0.0 | 0.0
26/05/2026 08:59 | 298.52 | 298.09 | 0.0 | 0.0
26/05/2026 08:59 | 298.52 | 298.29 | 0.0 | 0.0
26/05/2026 08:59 | 298.52 | 298.29 | 0.0 | 0.0
26/05/2026 08:59 | 298.48 | 298.29 | 0.0 | 0.0
26/05/2026 08:59 | 298.48 | 298.29 | 0.0 | 0.0
26/05/2026 08:59 | 298.53 | 298.16 | 0.0 | 0.0
26/05/2026 08:59 | 298.53 | 298.19 | 0.0 | 0.0
26/05/2026 08:59 | 298.58 | 298.26 | 0.0 | 0.0
26/05/2026 08:59 | 298.58 | 298.26 | 0.0 | 0.0
26/05/2026 08:59 | 298.53 | 298.27 | 0.0 | 0.0
26/05/2026 09:29 | -4177985.0 | 0.0 | 0.0 | 0.0
26/05/2026 09:29 | 0.0 | 0.0 | 0.0 | 0.0

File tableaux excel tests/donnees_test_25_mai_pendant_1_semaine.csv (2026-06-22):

Date/Heure | Balance 1 (g) | Balance 2 (g) | Balance 3 (g) | Balance 4 (g)
2026-05-26 10:10:06 | 299.69 | 309.63 | 0.0 | 0.0
2026-05-26 10:10:38 | 299.71 | 310.05 | 0.0 | 0.0
2026-05-26 16:06:16 | 299.92 | 308.67 | 0.0 | 0.0
2026-05-26 16:26:56 | 299.99 | 308.61 | 0.0 | 0.0
2026-05-26 16:27:01 | 299.97 | 308.6 | 0.0 | 0.0
2026-05-26 22:06:17 | 299.78 | 311.03 | 0.0 | 0.0
2026-05-27 04:06:22 | 299.64 | 310.55 | 0.0 | 0.0
2026-05-27 10:06:24 | 299.56 | 309.42 | 0.0 | 0.0
2026-05-27 16:06:27 | 299.58 | 308.63 | 0.0 | 0.0
2026-05-27 22:06:30 | 299.58 | 309.49 | 0.0 | 0.0
2026-05-28 04:06:33 | 64.3 | 308.49 | 0.0 | 0.0
2026-05-28 10:06:33 | 299.85 | 307.84 | 0.0 | 0.0
2026-05-28 16:06:34 | 299.83 | 306.43 | 0.0 | 0.0
2026-05-28 22:06:37 | 299.81 | 306.55 | 0.0 | 0.0
2026-05-29 04:06:39 | 299.84 | 306.96 | 0.0 | 0.0
2026-05-29 10:06:42 | 299.73 | 305.69 | 0.0 | 0.0
2026-05-29 16:06:44 | 299.82 | 304.7 | 0.0 | 0.0
2026-05-29 22:06:43 | 299.82 | 305.93 | 0.0 | 0.0
2026-05-30 04:06:45 | 299.83 | 305.62 | 0.0 | 0.0
2026-05-30 10:06:45 | 299.85 | 305.28 | 0.0 | 0.0
2026-05-30 16:06:44 | 299.75 | 305.43 | 0.0 | 0.0
2026-05-30 22:06:43 | 299.82 | 305.0 | 0.0 | 0.0
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

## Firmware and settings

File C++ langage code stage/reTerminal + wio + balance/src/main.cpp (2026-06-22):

// ============================================================
// Wio Terminal + HX711 (2 à 4 balances)
// Version V3.0 — SANS WIFI
// Communication via USB Serial vers reTerminal (Raspberry Pi)
//
// PROTOCOLE SERIAL :
//   Le Wio envoie toutes les 6h une ligne :
//   DATA,<poids_b1>,<poids_b2>,<poids_b3>,<poids_b4>
//   Exemple : DATA,48.72,32.15,0.00,0.00
//   0.00 = balance absente ou non connectée
//
//   Ce format est identique à ce que le Teensy enverra plus tard.
//   Le reTerminal n'aura pas besoin d'être modifié lors du remplacement.
//
// BOUTONS :
//   A        → Tare de la balance active
//   B        → Calibration de la balance active
//   C        → Basculer OVERVIEW / FOCUS
//   Gauche   → Balance active précédente
//   Droite   → Balance active suivante
//   Bas      → Envoyer les données maintenant (test)
//
// CHANGER L'INTERVALLE :
//   Ligne #define RECORD_INTERVAL_MS
//   6h  → 6UL  * 3600UL * 1000UL  (test)
//   24h → 24UL * 3600UL * 1000UL  (production)
// ============================================================

#include <Arduino.h>
#include <TFT_eSPI.h>
#include <HX711.h>
#include <stdarg.h>

// ============================================================
// CONFIG MATÉRIELLE
// ============================================================

#define NB_SCALES         4     // Nombre max de balances (changer si besoin)
#define CALIBRATION_MASS  100.0f

#define NB_SAMPLES        5
#define TARE_SAMPLES      40
#define CALIB_SAMPLES     80

#define DISPLAY_PERIOD_MS 300
#define DEBOUNCE_MS       150

#define ZERO_DEADBAND_G     0.05f
#define DISPLAY_DEADBAND_G  0.03f

const int COMMON_SCK_PIN         = D0;
const int DOUT_PINS[NB_SCALES]   = { D1, D2, D3, D4 };

// ============================================================
// CONFIG INTERVALLE
// 6h pour les tests, passer à 24h pour la production
// ============================================================

#define RECORD_INTERVAL_MS  (6UL * 3600UL * 1000UL)
// #define RECORD_INTERVAL_MS  (24UL * 3600UL * 1000UL)

// ============================================================
// VARIABLES GLOBALES
// ============================================================

float tare_offsets[NB_SCALES]        = {0.0f, 0.0f, 0.0f, 0.0f};
float calibration_factors[NB_SCALES] = {1.0f, 1.0f, 1.0f, 1.0f};

int  active_scale        = 0;
bool mode_focus          = false;
int  overview_read_index = 0;

float last_weights[NB_SCALES];
long  last_raws[NB_SCALES];
float displayed_weights[NB_SCALES];
bool  scale_present[NB_SCALES];

float last_drawn_weight[NB_SCALES] = {999999, 999999, 999999, 999999};
long  last_drawn_raw[NB_SCALES]    = {-999999, -999999, -999999, -999999};
int   last_drawn_active_scale      = -1;
bool  last_drawn_mode_focus        = false;

uint32_t last_record_ms = 0;

HX711    scales[NB_SCALES];
TFT_eSPI tft = TFT_eSPI();

// ============================================================
// COULEURS
// ============================================================

#define COLOR_TITLE    0x5D7F
#define COLOR_MODE     0xFFE0
#define COLOR_WHITE    TFT_WHITE
#define COLOR_GRAY     0x8410
#define COLOR_GREEN    0x07E0
#define COLOR_ORANGE   0xFD20
#define COLOR_STATUS   0x07E0
#define COLOR_RAW      0xAD55

// ============================================================
// POSITIONS ÉCRAN
// ============================================================

const int Y_TITLE  = 15;
const int Y_MODE   = 45;
const int Y_LINES[NB_SCALES] = { 75, 105, 135, 165 };
const int Y_BIG    = 95;
const int Y_RAW    = 165;
const int Y_CALIB  = 185;
const int Y_STATUS = 220;

char status_text[64] = "Demarrage...";

// ============================================================
// PROTOTYPES
// ============================================================

void draw_status_bar();
void draw_static_screen();
void update_display_values();
void force_full_redraw();
void send_data_serial();

// ============================================================
// STATUS BAR
// ============================================================

void set_statusf(const char* fmt, ...) {
    va_list args;
    va_start(args, fmt);
    vsnprintf(status_text, sizeof(status_text), fmt, args);
    va_end(args);
    Serial.flush(); // Ne pas interrompre un envoi de données
    draw_status_bar();
}

// ============================================================
// BOUTONS
// ============================================================

struct ButtonEdge {
    int      pin;
    bool     last_state;
    uint32_t last_event_time_ms;

    void begin(int p) {
        pin = p;
        pinMode(pin, INPUT_PULLUP);
        last_state = (digitalRead(pin) == LOW);
        last_event_time_ms = 0;
    }

    bool fell() {
        uint32_t now = millis();
        bool current = (digitalRead(pin) == LOW);
        bool event = false;
        if (current && !last_state) {
            if (now - last_event_time_ms >= DEBOUNCE_MS) {
                event = true;
                last_event_time_ms = now;
            }
        }
        last_state = current;
        return event;
    }

    bool is_pressed() {
        return (digitalRead(pin) == LOW);
    }
};

ButtonEdge btn_a, btn_b, btn_c, btn_left, btn_right, btn_down;

// ============================================================
// DÉTECTION HX711
// ============================================================

bool hx711_detect_dout(int dout_pin, unsigned long timeout_ms = 1000) {
    pinMode(dout_pin, INPUT);
    pinMode(COMMON_SCK_PIN, OUTPUT);
    digitalWrite(COMMON_SCK_PIN, LOW);

    unsigned long start = millis();
    while (millis() - start < timeout_ms) {
        if (digitalRead(dout_pin) == LOW) return true;
        delay(10);
    }
    return false;
}

// ============================================================
// MESURES
// ============================================================

long read_raw_average(int index, int n = NB_SAMPLES) {
    if (index < 0 || index >= NB_SCALES) return 0;
    if (!scale_present[index]) return last_raws[index];

    long total = 0;
    int valid = 0;

    for (int i = 0; i < n; i++) {
        if (scales[index].is_ready()) {
            total += scales[index].read();
            valid++;
        }
        delay(3);
    }

    return (valid == 0) ? last_raws[index] : total / valid;
}

long read_raw_average_exact(int index, int n, const char* label) {
    if (index < 0 || index >= NB_SCALES) return 0;
    if (!scale_present[index]) return 0;

    long total = 0;
    int valid = 0;

    while (valid < n) {
        unsigned long wait_start = millis();
        while (!scales[index].is_ready()) {
            if (millis() - wait_start > 1200) {
                if (valid > 0) { set_statusf("%s timeout %d/%d", label, valid, n); return total / valid; }
                else           { set_statusf("%s timeout 0/%d", label, n); return last_raws[index]; }
            }
            delay(1);
        }
        total += scales[index].read();
        valid++;
        if (valid % 10 == 0 || valid == n) set_statusf("%s %d/%d", label, valid, n);
        delay(1);
    }
    return total / valid;
}

float raw_to_weight(int index, long raw) {
    if (index < 0 || index >= NB_SCALES) return 0.0f;
    float factor = calibration_factors[index];
    if (factor == 0.0f) return 0.0f;
    float weight = (float)(raw - (long)tare_offsets[index]) / factor;
    if (abs(weight) < ZERO_DEADBAND_G) weight = 0.0f;
    return weight;
}

void read_weight(int index) {
    if (index < 0 || index >= NB_SCALES) return;
    if (!scale_present[index]) {
        last_weights[index] = 0.0f;
        last_raws[index] = 0;
        return;
    }
    long raw = read_raw_average(index, NB_SAMPLES);
    last_raws[index] = raw;
    last_weights[index] = raw_to_weight(index, raw);
}

float stable_display_weight(int index) {
    if (index < 0 || index >= NB_SCALES) return 0.0f;
    float weight = last_weights[index];
    float old = displayed_weights[index];
    if (abs(weight - old) >= DISPLAY_DEADBAND_G) displayed_weights[index] = weight;
    return displayed_weights[index];
}

// ============================================================
// TARE / CALIBRATION
// ============================================================

void tare(int index) {
    if (index < 0 || index >= NB_SCALES) return;
    if (!scale_present[index]) { set_statusf("B%d absente", index + 1); return; }

    set_statusf("Tare B%d: ne touche plus", index + 1);
    delay(1200);
    long raw = read_raw_average_exact(index, TARE_SAMPLES, "Tare");
    last_raws[index] = raw;
    tare_offsets[index] = (float)raw;
    last_weights[index] = 0.0f;
    displayed_weights[index] = 0.0f;
    last_drawn_weight[index] = 999999;
    last_drawn_raw[index] = -999999;
    set_statusf("Tare B%d OK", index + 1);
    update_display_values();
    delay(800);
}

void wait_release_b() { while (btn_b.is_pressed()) delay(20); delay(DEBOUNCE_MS); }
void wait_press_b()   { while (!btn_b.is_pressed()) delay(20); delay(DEBOUNCE_MS); }
void wait_b_click()   { wait_release_b(); wait_press_b(); wait_release_b(); }

void calibrate_0_100g(int index) {
    if (index < 0 || index >= NB_SCALES) return;
    if (!scale_present[index]) { set_statusf("B%d absente", index + 1); return; }

    set_statusf("Calib B%d: vide puis B", index + 1);
    wait_b_click();
    set_statusf("0g: ne touche plus");
    delay(1500);
    long raw_0g = read_raw_average_exact(index, CALIB_SAMPLES, "Mesure 0g");
    last_raws[index] = raw_0g;
    tare_offsets[index] = (float)raw_0g;
    displayed_weights[index] = 0.0f;
    last_weights[index] = 0.0f;
    last_drawn_weight[index] = 999999;
    last_drawn_raw[index] = -999999;
    set_statusf("0g OK");
    update_display_values();
    delay(1000);

    set_statusf("Pose %.0fg puis B", CALIBRATION_MASS);
    wait_b_click();
    set_statusf("%.0fg: ne touche plus", CALIBRATION_MASS);
    delay(1500);
    long raw_ref = read_raw_average_exact(index, CALIB_SAMPLES, "Mesure masse");
    last_raws[index] = raw_ref;
    long diff = raw_ref - raw_0g;

    if (abs(diff) < 10) { set_statusf("Erreur calib diff=%ld", diff); return; }

    calibration_factors[index] = (float)diff / CALIBRATION_MASS;
    last_weights[index] = CALIBRATION_MASS;
    displayed_weights[index] = CALIBRATION_MASS;
    last_drawn_weight[index] = 999999;
    last_drawn_raw[index] = -999999;
    set_statusf("Calib B%d OK f=%.2f", index + 1, calibration_factors[index]);
    update_display_values();
    delay(1200);
}

// ============================================================
// NAVIGATION
// ============================================================

void change_active_scale(int direction) {
    active_scale = (active_scale + direction + NB_SCALES) % NB_SCALES;
    snprintf(status_text, sizeof(status_text), "Balance active: B%d", active_scale + 1);
}

// ============================================================
// ENVOI DONNÉES VIA SERIAL (USB vers reTerminal)
// ============================================================

void send_data_serial() {
    // Lire toutes les balances une dernière fois avant d'envoyer
    for (int i = 0; i < NB_SCALES; i++) {
        read_weight(i);
    }

    // Format : DATA,<b1>,<b2>,<b3>,<b4>
    // 0.00 si la balance est absente
    Serial.print("DATA");
    for (int i = 0; i < NB_SCALES; i++) {
        Serial.print(",");
        if (scale_present[i]) {
            Serial.print(stable_display_weight(i), 2);
        } else {
            Serial.print("0.00");
        }
    }
    Serial.println(); // \n final — le reTerminal lit jusqu'au \n

    // Affichage sur l'écran
    unsigned long h = (millis() / 1000) / 3600;
    unsigned long m = ((millis() / 1000) % 3600) / 60;
    set_statusf("Envoye T+%02luh%02lu | BAS=forcer", h, m);
}

// ============================================================
// AFFICHAGE
// ============================================================

void reset_draw_cache() {
    for (int i = 0; i < NB_SCALES; i++) {
        last_drawn_weight[i] = 999999;
        last_drawn_raw[i]    = -999999;
    }
    last_drawn_active_scale = active_scale;
    last_drawn_mode_focus   = mode_focus;
}

void draw_status_bar() {
    tft.fillRect(0, Y_STATUS, 320, 20, TFT_BLACK);
    tft.setTextColor(COLOR_STATUS, TFT_BLACK);
    tft.setTextSize(1);
    tft.setCursor(10, Y_STATUS);
    tft.print(status_text);
}

void draw_static_screen() {
    tft.fillScreen(TFT_BLACK);
    tft.setTextColor(COLOR_TITLE, TFT_BLACK);
    tft.setTextSize(2);
    tft.setCursor(10, Y_TITLE);

    if (mode_focus) {
        tft.printf("Balance B%d", active_scale + 1);
        tft.setTextColor(COLOR_MODE, TFT_BLACK);
        tft.setTextSize(1);
        tft.setCursor(10, Y_MODE);
        tft.print("FOCUS | A tare | B calib | C overview");
    } else {
        tft.print("Balances HX711");
        tft.setTextColor(COLOR_MODE, TFT_BLACK);
        tft.setTextSize(1);
        tft.setCursor(10, Y_MODE);
        tft.print("OVERVIEW | A tare | B calib | C focus");
    }

    // Indicateur de prochaine mesure
    tft.setTextColor(COLOR_ORANGE, TFT_BLACK);
    tft.setTextSize(1);
    tft.setCursor(10, Y_MODE + 15);

    unsigned long next_ms = RECORD_INTERVAL_MS - (millis() - last_record_ms);
    unsigned long next_h  = (next_ms / 1000) / 3600;
    unsigned long next_m  = ((next_ms / 1000) % 3600) / 60;
    tft.printf("Prochain envoi dans %02luh%02lu | BAS=forcer", next_h, next_m);

    if (mode_focus) {
        tft.setTextColor(COLOR_RAW, TFT_BLACK);
        tft.setTextSize(1);
        tft.setCursor(10, Y_RAW);
        tft.print("RAW:");
        tft.setCursor(10, Y_CALIB);
        tft.print("Calib:");
    }

    draw_status_bar();
}

void force_full_redraw() {
    draw_static_screen();
    reset_draw_cache();
    update_display_values();
}

void update_display_values() {
    if (mode_focus) {
        if (!scale_present[active_scale]) {
            tft.setTextColor(COLOR_WHITE, TFT_BLACK);
            tft.setTextSize(4);
            tft.setCursor(10, Y_BIG);
            tft.print("Absente    ");
            return;
        }

        float shown = stable_display_weight(active_scale);
        long  raw   = last_raws[active_scale];

        if (abs(shown - last_drawn_weight[active_scale]) >= DISPLAY_DEADBAND_G) {
            tft.setTextColor(COLOR_WHITE, TFT_BLACK);
            tft.setTextSize(4);
            tft.setCursor(10, Y_BIG);
            tft.printf("%10.2f g", shown);
            last_drawn_weight[active_scale] = shown;
        }

        if (raw != last_drawn_raw[active_scale]) {
            tft.setTextColor(COLOR_RAW, TFT_BLACK);
            tft.setTextSize(1);
            tft.setCursor(50, Y_RAW);
            tft.printf("%-16ld", raw);
            tft.setCursor(60, Y_CALIB);
            tft.printf("%-12.2f", calibration_factors[active_scale]);
            last_drawn_raw[active_scale] = raw;
        }
    } else {
        bool active_changed = (last_drawn_active_scale != active_scale);

        for (int i = 0; i < NB_SCALES; i++) {
            float shown = stable_display_weight(i);

            if (active_changed || abs(shown - last_drawn_weight[i]) >= DISPLAY_DEADBAND_G) {
                tft.setTextSize(2);
                tft.setCursor(10, Y_LINES[i]);

                if (!scale_present[i]) {
                    tft.setTextColor(COLOR_GRAY, TFT_BLACK);
                    tft.printf(" B%d: absente       ", i + 1);
                } else {
                    char prefix = (i == active_scale) ? '>' : ' ';
                    tft.setTextColor(i == active_scale ? COLOR_GREEN : COLOR_WHITE, TFT_BLACK);
                    tft.printf("%cB%d: %7.2f g   ", prefix, i + 1, shown);
                }
                last_drawn_weight[i] = shown;
            }
        }
        last_drawn_active_scale = active_scale;
    }
}

// ============================================================
// MISE À JOUR COMPTEUR UNIQUEMENT (sans redessiner l'écran)
// ============================================================

void update_countdown() {
    unsigned long elapsed = millis() - last_record_ms;
    unsigned long remaining_ms = (elapsed >= RECORD_INTERVAL_MS) ? 0 : RECORD_INTERVAL_MS - elapsed;
    unsigned long next_h = (remaining_ms / 1000) / 3600;
    unsigned long next_m = ((remaining_ms / 1000) % 3600) / 60;

    // Efface uniquement la ligne du compteur
    tft.fillRect(0, Y_MODE + 15, 320, 12, TFT_BLACK);
    tft.setTextColor(COLOR_ORANGE, TFT_BLACK);
    tft.setTextSize(1);
    tft.setCursor(10, Y_MODE + 15);
    tft.printf("Prochain envoi dans %02luh%02lu | BAS=forcer", next_h, next_m);
}

// ============================================================
// SETUP
// ============================================================

void setup() {
    Serial.begin(115200);

    tft.begin();
    tft.setRotation(3);
    tft.fillScreen(TFT_BLACK);

    btn_a.begin(WIO_KEY_A);
    btn_b.begin(WIO_KEY_B);
    btn_c.begin(WIO_KEY_C);
    btn_left.begin(WIO_5S_LEFT);
    btn_right.begin(WIO_5S_RIGHT);
    btn_down.begin(WIO_5S_DOWN);

    for (int i = 0; i < NB_SCALES; i++) {
        last_weights[i]      = 0.0f;
        last_raws[i]         = 0;
        displayed_weights[i] = 0.0f;

        if (hx711_detect_dout(DOUT_PINS[i])) {
            scales[i].begin(DOUT_PINS[i], COMMON_SCK_PIN);
            scale_present[i] = true;
        } else {
            scale_present[i] = false;
        }
    }

    force_full_redraw();

    // Première mesure immédiate au démarrage
    send_data_serial();
    last_record_ms = millis();

    set_statusf("Pret - BAS pour forcer envoi");
}

// ============================================================
// LOOP
// ============================================================

uint32_t last_display_ms  = 0;
uint32_t last_countdown_ms = 0;
#define  COUNTDOWN_PERIOD_MS 30000

void loop() {
    // ─── Boutons ────────────────────────────────────────────
    if (btn_a.fell()) tare(active_scale);
    if (btn_b.fell()) calibrate_0_100g(active_scale);

    if (btn_c.fell()) {
        mode_focus = !mode_focus;
        snprintf(status_text, sizeof(status_text),
                 "Mode %s", mode_focus ? "FOCUS" : "OVERVIEW");
        force_full_redraw();
    }

    // Joystick BAS = forcer l'envoi immédiatement (le compteur continue)
    if (btn_down.fell()) {
        send_data_serial();
        // last_record_ms inchangé → le compteur 6h continue normalement
    }

    if (btn_right.fell()) {
        change_active_scale(1);
        if (mode_focus) force_full_redraw();
        else { update_display_values(); draw_status_bar(); }
    }

    if (btn_left.fell()) {
        change_active_scale(-1);
        if (mode_focus) force_full_redraw();
        else { update_display_values(); draw_status_bar(); }
    }

    // ─── Lecture capteurs ────────────────────────────────────
    if (mode_focus) {
        read_weight(active_scale);
    } else {
        read_weight(overview_read_index);
        overview_read_index = (overview_read_index + 1) % NB_SCALES;
    }

    // ─── Affichage périodique ─────────────────────────────────
    if (millis() - last_display_ms >= DISPLAY_PERIOD_MS) {
        update_display_values();
        last_display_ms = millis();
    }

    // ─── Mise à jour compteur toutes les 30s (sans clignotement) ─
    if (millis() - last_countdown_ms >= COUNTDOWN_PERIOD_MS) {
        update_countdown();
        last_countdown_ms = millis();
    }

    // ─── Envoi automatique toutes les 6h ─────────────────────
    if (millis() - last_record_ms >= RECORD_INTERVAL_MS) {
        send_data_serial();
        last_record_ms = millis();
    }

    delay(10);
}

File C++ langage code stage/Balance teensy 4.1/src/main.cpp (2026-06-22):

// ============================================================
// Teensy 4.1 — 24 balances HX711
// SCK commun pin 2 | DOUT pins 3-26
// UART vers reTerminal : Serial1 (TX pin 1) à 115200 baud
//
// Format trame envoyée toutes les SEND_INTERVAL_MS :
// B1:228,50;B2:ERR;B3:145,30;...;B24:ERR\n
//
// Calibration stockée en EEPROM — survit aux reboots
// Balance absente → marqueur ERR dans la trame
// ============================================================

#include <Arduino.h>
#include <HX711.h>
#include <EEPROM.h>

// ============================================================
// CONFIG
// ============================================================

#define NB_SCALES           24
#define COMMON_SCK_PIN       2

// DOUT pins : B1=pin3, B2=pin4, ..., B24=pin27
const int DOUT_PINS[NB_SCALES] = {
     3,  4,  5,  6,  7,  8,  9, 10, 11, 12,
    14, 15, 16, 17, 18, 19, 20, 21, 22, 23,
    24, 25, 26, 27
};

#define NB_SAMPLES          5
#define TARE_SAMPLES        40
#define CALIB_SAMPLES       80
#define CALIBRATION_MASS    100.0f
#define ZERO_DEADBAND_G     0.05f
#define SEND_INTERVAL_MS    5000

// ============================================================
// EEPROM
// ============================================================

#define EEPROM_BASE_TARE    0
#define EEPROM_BASE_FACTOR  (NB_SCALES * sizeof(float))

void eeprom_save_tare(int i, float v)   { EEPROM.put(EEPROM_BASE_TARE   + i * sizeof(float), v); }
void eeprom_save_factor(int i, float v) { EEPROM.put(EEPROM_BASE_FACTOR + i * sizeof(float), v); }

float eeprom_load_tare(int i) {
    float v; EEPROM.get(EEPROM_BASE_TARE + i * sizeof(float), v);
    return (isnan(v) || isinf(v)) ? 0.0f : v;
}
float eeprom_load_factor(int i) {
    float v; EEPROM.get(EEPROM_BASE_FACTOR + i * sizeof(float), v);
    return (isnan(v) || isinf(v) || v == 0.0f) ? 1.0f : v;
}

// ============================================================
// VARIABLES GLOBALES
// ============================================================

HX711    scales[NB_SCALES];
bool     scale_present[NB_SCALES];
float    tare_offsets[NB_SCALES];
float    calibration_factors[NB_SCALES];
float    last_weights[NB_SCALES];
long     last_raws[NB_SCALES];
uint32_t last_send_ms    = 0;
uint32_t send_interval_ms = SEND_INTERVAL_MS;
int      read_index      = 0;

// ============================================================
// DETECTION HX711 — simple et fiable
//
// Principe : un HX711 connecté met DOUT à LOW quand il a
// une donnée prête (toutes les ~100 ms à 10 Hz).
// Avec INPUT_PULLUP, un pin non connecté reste HIGH.
// On attend juste un LOW franc pendant 1200 ms max.
// Ensuite on tente une vraie lecture pour confirmer.
// ============================================================

bool hx711_detect(int index) {
    int dout = DOUT_PINS[index];

    // SCK LOW = mode normal (pas de power-down)
    pinMode(COMMON_SCK_PIN, OUTPUT);
    digitalWrite(COMMON_SCK_PIN, LOW);

    // DOUT en entrée avec pull-up : pin flottant → reste HIGH
    pinMode(dout, INPUT_PULLUP);
    delay(10);

    // Étape 1 : attendre DOUT LOW (HX711 données prêtes)
    // Si rien au bout de 1200 ms → absent
    unsigned long t = millis();
    bool got_low = false;
    while (millis() - t < 1200) {
        if (digitalRead(dout) == LOW) { got_low = true; break; }
        delay(10);
    }
    if (!got_low) return false;

    // Étape 2 : initialiser et tenter une lecture réelle
    // Si le HX711 est là, read() renvoie une valeur 24 bits non nulle
    scales[index].begin(dout, COMMON_SCK_PIN);
    delay(10);

    if (!scales[index].is_ready()) return false;

    long val = scales[index].read();

    // Une valeur brute de 0 exact ou très proche de 0x7FFFFF (saturé)
    // indique un problème — on accepte tout le reste
    if (val == 0 || val == 0x7FFFFF || val == -0x800000) return false;

    return true;
}

// ============================================================
// LECTURE RAW
// ============================================================

long read_raw_average(int index, int n) {
    if (!scale_present[index]) return last_raws[index];
    long total = 0; int valid = 0;
    for (int i = 0; i < n; i++) {
        if (scales[index].is_ready()) { total += scales[index].read(); valid++; }
        delay(3);
    }
    return (valid == 0) ? last_raws[index] : total / valid;
}

long read_raw_exact(int index, int n) {
    if (!scale_present[index]) return 0;
    long total = 0; int valid = 0;
    while (valid < n) {
        unsigned long w = millis();
        while (!scales[index].is_ready()) {
            if (millis() - w > 1500) return (valid > 0) ? total / valid : last_raws[index];
            delay(1);
        }
        total += scales[index].read();
        valid++;
        delay(1);
    }
    return total / valid;
}

// ============================================================
// POIDS
// ============================================================

float raw_to_weight(int index, long raw) {
    float factor = calibration_factors[index];
    if (factor == 0.0f) return 0.0f;
    float w = (float)(raw - (long)tare_offsets[index]) / factor;
    if (fabsf(w) < ZERO_DEADBAND_G) w = 0.0f;
    return w;
}

void read_weight(int index) {
    if (!scale_present[index]) { last_weights[index] = -1.0f; last_raws[index] = 0; return; }
    long raw = read_raw_average(index, NB_SAMPLES);
    last_raws[index]    = raw;
    last_weights[index] = raw_to_weight(index, raw);
}

// ============================================================
// TARE
// ============================================================

void tare(int index) {
    if (!scale_present[index]) { Serial1.printf("# TARE B%d : absente\n", index+1); return; }
    Serial1.printf("# TARE B%d : mesure en cours...\n", index+1);
    delay(500);
    long raw = read_raw_exact(index, TARE_SAMPLES);
    tare_offsets[index] = (float)raw;
    last_raws[index]    = raw;
    last_weights[index] = 0.0f;
    eeprom_save_tare(index, tare_offsets[index]);
    Serial1.printf("# TARE B%d : OK (raw=%ld)\n", index+1, raw);
}

// ============================================================
// CALIBRATION
// ============================================================
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

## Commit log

2026-06-05 Revise README with project information and features
    Updated project details and added sections for context, architecture, hardware used, wiring, and features.
2026-06-22 sync : ajout complet des fichiers locaux
    [balance socle v4.stl, balance socle.stl, balance top trou de vis 10mm.stl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]
